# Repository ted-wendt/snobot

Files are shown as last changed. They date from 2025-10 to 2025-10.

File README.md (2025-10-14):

# Project Sno-bot
A modular, Raspberry-Pi–driven sidewalk snow-removal robot designed for Helena, MT conditions. This repo is organized for **clarity, reproducibility, and future contributions**.

## Highlights
- **Modular Toolhead Interface**: swap plow, brush, or blower without rewiring
- **Teleop → Autonomy Path**: same electronics, two software modes
- **Pi-first, lightweight ML**: semantic segmentation on-device; TFLite/ONNX
- **Safety-first**: E‑stop, contactor, current-based jam detection

## Repo Layout
```
project-sno-bot/
├── README.md
├── LICENSE
├── .gitignore
├── docs/
│   ├── architecture.md
│   ├── toolhead_interface.md
│   ├── autonomy_plan.md
│   ├── casting_planner.md
│   └── vision_pipeline.md
├── electronics/
│   ├── parts_list.md
│   ├── wiring.md
│   └── schematics/   (place PDFs/PNGs here)
├── firmware/
│   └── toolhead_mcu/
│       ├── README.md
│       └── examples/
│           ├── i2c_api_sketch.ino
│           ├── can_api_sketch.md
│           └── id_eeprom_schema.json
├── software/
│   ├── pi/
│   │   ├── toolhead_manager.py
│   │   ├── teleop_controller.py
│   │   ├── requirements.txt
│   │   └── examples/
│   │       └── demo_run.py
│   └── training/
│       ├── dataset_prep.md
│       ├── fastscnn_train_stub.py
│       └── export_to_tflite.md
└── mechanical/
    ├── mount_interface.md
    └── references.md
```

## Quick Start
1. **Clone** this repo and open `docs/architecture.md`.
2. **Electronics**: follow `electronics/parts_list.md` and `electronics/wiring.md`.
3. **Firmware**: flash `firmware/toolhead_mcu/examples/i2c_api_sketch.ino` to your toolhead MCU.
4. **Software (Pi)**: install `software/pi/requirements.txt` then run `examples/demo_run.py`.
5. **Vision**: see `docs/vision_pipeline.md` and `software/training/` for segmentation training.

## License
MIT — see `LICENSE`.

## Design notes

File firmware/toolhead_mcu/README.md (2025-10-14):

# Toolhead MCU

Provide a uniform API to the Pi regardless of attachment (brush/thrower/plow).

- Enforce local safety (overcurrent → FAULT)
- Jam clear routine (reverse X ms, retry N)
- Servo control for chute/deflector
- Report: type, currents, rpm, temp, faults

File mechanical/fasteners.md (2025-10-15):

# Fasteners & Hardware

## T-slot
- Roll-in spring T-nuts, M5: 60 pcs
- Button head M5 x 10 mm: 60 pcs
- Corner bracket kits (include bolts & T-nuts): 12–20 kits

## Through-bolts
- M6 x 16/20 mm + washers + nyloc (nose plate): 6 pcs
- M5 x 12/16 mm + washers + nyloc (belly pan): 8 pcs
- Add M6 for gussets/front bar: 8 pcs

## Bearings/Shafts (if jackshafts)
- Pillow blocks UCP201 (12 mm) or UCP202 (15 mm): 4 pcs
- Keyed shaft 12–15 mm: 2 short lengths
- Shaft collars (matching ID): 4 pcs

## Notes
- Prefer stainless hardware where exposed; blue Loctite 243; anti-seize for stainless.
- Heat-set inserts (M3/M4) for printed parts.

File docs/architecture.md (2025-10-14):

# System Architecture

## Goals
- Helena snowbanks: must **lift/throw** snow (not just push)
- **Modular toolhead** with uniform electrical + software interface
- **Teleop now, autonomy later** without electronics redo

## High-Level Diagram
- **Compute**: Raspberry Pi (teleop + autonomy)
- **Traction**: Pololu motor HAT (left/right)
- **Toolhead**: Swappable module with its own MCU + drivers
  - BLDC impeller via **VESC** (UART/CAN)
  - Brushed DC auger/actuators via **H-bridge**
  - Servos (chute/deflector) via PCA9685 or MCU PWM
- **Safety**: E‑stop → DC contactor; guard/cover interlock; current sensing
- **Perception**: mono camera → segmentation (Fast‑SCNN/ENet) → drivable ribbon
- **Localization**: wheel odom + IMU (optional LiDAR later)
- **Planner**: centerline follow + “no‑throw” map → chute angles

## Operating Modes
- **DISARMED** → **ARMED** → **TELEOP** or **AUTO** → **FAULT**/E‑STOP
- Teleop has priority; MCU enforces current limits + jam clear.

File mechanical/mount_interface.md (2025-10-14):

# Mechanical Mount Interface (Draft)
- Quick‑attach face plate with 4× M6 slots, 50×50 mm pattern
- Datum surface 20 mm above ground; adjustable skid shoes ±10 mm
- Cable strain relief + IP‑rated connector orientation downward

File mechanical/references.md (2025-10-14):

# Mechanical References
- Snow blower single‑stage paddle geometries
- Off‑the‑shelf scooter BLDCs for impellers
- 80/20 aluminum extrusions for brackets

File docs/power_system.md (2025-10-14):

# Power System (24 V Toolhead Rail + 5 V Logic)

This guide covers a robust, reproducible power setup for Sno‑bot.

## Architecture Overview
- **Toolhead Rail:** 24–26 V (preferred: **8S LiFePO₄ 25.6 V** or **6S LiPo 22.2 V**)
- **Logic/Compute:** 5 V from a high‑quality buck converter (≥5–8 A)
- **Traction:** share the 24 V rail (separate motor drivers) _or_ keep 12 V during early tests
- **Isolation:** separate toolhead rail from logic; common ground at a star point

```
Battery (24–26 V) → Main Fuse (40–60 A) → Contactor (E‑STOP) →
    ├─ VESC (BLDC impeller/brush)
    ├─ H‑Bridge (brushed auger/actuators)
    ├─ Buck 24→5 V (Pi/servos/sensors)
    └─ Optional Buck 24→12 V (lights, relays)
```

## Sizing & Budget
Typical continuous power while clearing: **500–1200 W**.
- Drive (2 wheels): 80–200 W cruise; 400–600 W spikes on pivots
- Toolhead: 300–1200 W depending on brush/single‑stage/two‑stage
- Electronics: 10–20 W

**Runtime example** (24 V × 20 Ah LiFePO₄ ≈ 512 Wh; ~85% usable ≈ 435 Wh):
- Light: 350 W → ~1.24 h
- Moderate: 600 W → ~0.72 h
- Heavy: 1000 W → ~0.44 h

## Chemistry Choices
| Chemistry | Pros | Cons | Notes |
|---|---|---|---|
| **LiFePO₄ (8S, 25.6 V)** | Safe, long cycle life, integrated BMS | Heavier; **don’t charge <0 °C** | Best for reproducible builds |
| **LiPo (6S, 22.2 V)** | Light, high C, cheap | Touchier safety, cold sag, no BMS | Fine for prototypes & short demos |
| **Li‑ion (6–7S)** | Good energy density | Pack build complexity | Viable if you already build packs |

## Cold‑Weather Guidance
- **Don’t charge LiFePO₄ below 0 °C.** Discharge is OK with reduced capacity.
- Insulate the battery; add a **5–10 W heater pad** with a **5 °C thermostat**.
- Use **soft‑start** on toolhead motors (VESC ramp; H‑bridge PWM ramp).

## Current, Wire, Fusing
- Size for **50–60 A** bursts at 24 V.
- **Main fuse:** 40–60 A (MIDI/ANL) close to the battery.
- **Contactor/relay:** DC‑rated ≥60 A on 24 V.
- **Wire:** 10 AWG for 30–40 A runs; 8 AWG if long. Keep logic wiring separate/twisted.
- **Connectors:** **XT90‑S (anti‑spark)** or **Anderson SB50** on the toolhead rail.

## Safety Chain
- Physical **E‑STOP** in series with the **contactor coil**.
- **Guard/cover switch** in the ENABLE loop to prevent spin when open.
- **Current sensors** (INA226/ACS758) to detect jams; auto‑reverse auger.

## Using Your Existing 3S 11.1 V 5 Ah Packs
- Two in series = **6S 22.2 V 5 Ah ≈ 111 Wh** → short demos.
- For production, move to a **single 24 V LiFePO₄ pack with BMS** (20–30 Ah).

## Checklists

### Bring‑Up
- [ ] Battery secured, insulated, and strain‑relieved
- [ ] Main fuse within 10 cm of battery positive
- [ ] Contactor wired through E‑STOP and key/arm switch
- [ ] Star ground near contactor; logic return routed separately
- [ ] Buck converters mounted with airflow
- [ ] Current sensors calibrated (zero, scale)
- [ ] ESC/H‑bridge soft‑start verified; no brownouts on spin‑up

### Field Operation
- [ ] Battery at room temperature before charging
- [ ] Visual inspection for damaged chains/wires
- [ ] E‑STOP test before engaging toolhead
- [ ] Logs enabled for current, voltage, RPM (for later tuning)

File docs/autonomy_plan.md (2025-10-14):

# Autonomy Plan

## Perception
- Binary semantic segmentation: **sidewalk vs non‑sidewalk**
- Model: **Fast‑SCNN / ENet / BiSeNetV2** at 384×192 or 512×256
- Export: **TFLite INT8** or **ONNX**

## Post‑Processing
- Morphological clean → largest component near bottom
- Row‑wise centroid → polynomial centerline
- Chute planner: segment‑based allowed azimuth ranges

## Mapping
- Pre‑season clear‑ground mapping: mark **no‑throw** polygons and **dump zones**
- During storm: align via odom/IMU; optional VO/LiDAR later

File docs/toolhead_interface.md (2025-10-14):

# Toolhead Interface (Electrical + Software)

## Electrical Connector (example)
- Power: **+V_tool**, **GND**
- Safety: **ENABLE loop** (series with E‑stop + guard switch)
- Bus: **I²C** (SDA/SCL) *or* **CAN** (H/L)
- Aux: 2–4 pins for PWM/DIR/servo if needed
- ID: analog ID pin *or* I²C EEPROM (24LC02) with JSON blob

## Toolhead MCU Responsibilities
- Drive local motors (VESC over UART/CAN; H‑bridge PWM/DIR)
- Servo control for chute/deflector
- Read sensors (current, RPM, temp, lid)
- Implement **state machine**: IDLE → SPINUP → RUN → JAM_CLEAR → FAULT
- Expose uniform API to Pi

## Uniform API (I²C example)
- `0x01 SET_ENABLE {0|1}`
- `0x02 SET_THROTTLE {-100..100}` (or `SET_RPM` for BLDC)
- `0x03 SET_DIR {FWD|REV}`
- `0x04 SET_CHUTE_DEG {0..360}`
- `0x05 SET_DEFLECT_PCT {0..100}`
- `0x10 GET_STATUS` → currents, rpm, temp, faults, type

See `firmware/toolhead_mcu/examples/i2c_api_sketch.ino`.

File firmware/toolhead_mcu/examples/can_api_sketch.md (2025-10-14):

# CAN API Sketch
If you choose CANbus, mirror the same commands with 11-bit IDs:
- 0x100: SET_ENABLE, payload 1 byte
- 0x101: SET_THROTTLE, payload 1 byte (signed)
- 0x102: SET_DIR, payload 1 byte
- 0x103: SET_CHUTE, payload 2 bytes (deg)
- 0x104: SET_DEFLECT, payload 1 byte
- 0x180: GET_STATUS → periodic 10 Hz frame (currents, rpm, temp, faults)

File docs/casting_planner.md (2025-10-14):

# Casting Planner (Snow Throw Direction)

## Inputs
- Segment ID (from route)
- Wind (optional)
- No‑throw polygons
- Bank height estimate (optional, later)

## Outputs
- Chute azimuth (deg) + deflector (%)
- Safety check: if no safe azimuth, pause and re‑approach

## State Sketch
- `APPROACH` → `CAST_ALLOWED?` → `SET_AZIMUTH` → `TRACK_SEGMENT` → loop

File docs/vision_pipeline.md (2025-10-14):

# Vision Pipeline

## Dataset
- ~300 images of snow‑covered sidewalks
- Masks labeled as `sidewalk`

## Augmentations
- Brightness/contrast/gamma, light blur, noise
- Haze/fog, low‑contrast variants
- Small rotations, flips if context allows

## Training (PyTorch)
- Loss: BCEWithLogits + Dice (or Focal + Dice)
- Optim: AdamW, LR 3e‑4, 50–100 epochs
- Metric: IoU on sidewalk class

## Export
- PyTorch → ONNX → TFLite INT8 (post‑training quant)

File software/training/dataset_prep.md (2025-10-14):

# Dataset Preparation
- Use CVAT/LabelMe to annotate sidewalks → binary masks.
- Split 70/15/15 train/val/test by scene (avoid leakage).
- Resize to 384×192 or 512×256; save RGB + mask pairs.

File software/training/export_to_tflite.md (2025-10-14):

# Export to TFLite
- Export PyTorch → ONNX (opset 12)
- Convert ONNX → TF SavedModel → TFLite (INT8 post‑training)
- Copy .tflite to Pi and run via tflite-runtime

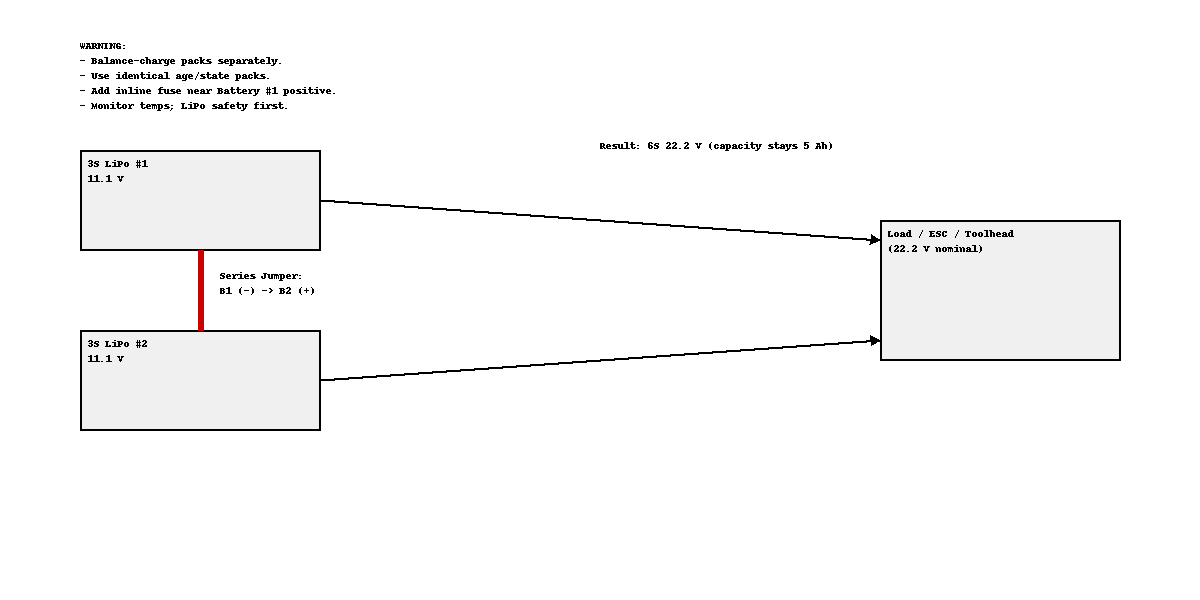
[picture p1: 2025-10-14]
electronics/schematics/series_harness_2x3S_to_6S.png

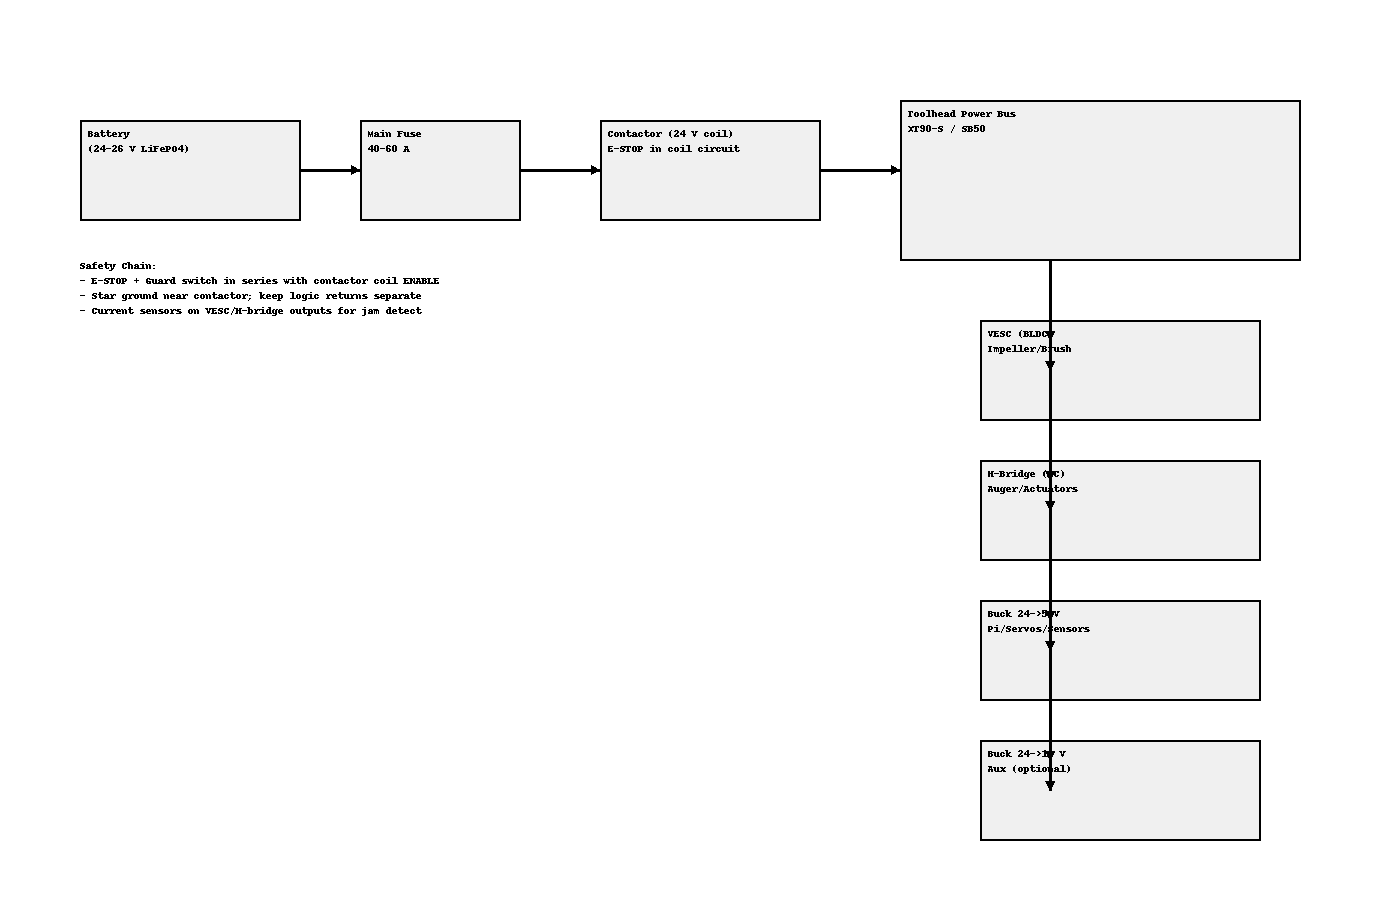
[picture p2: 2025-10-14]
electronics/schematics/power_overview_schematic.png

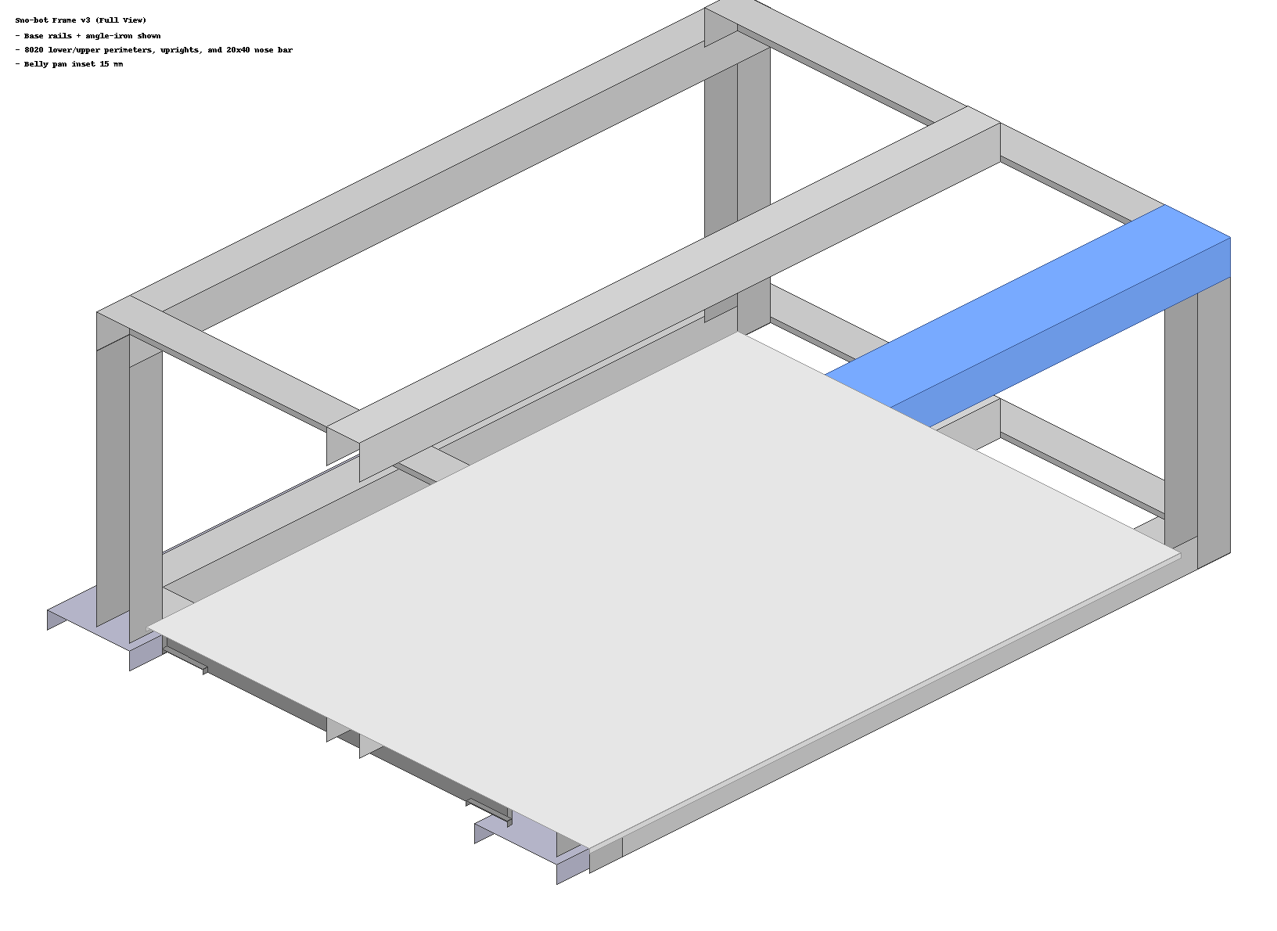
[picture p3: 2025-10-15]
docs/frame_visual_v3.png

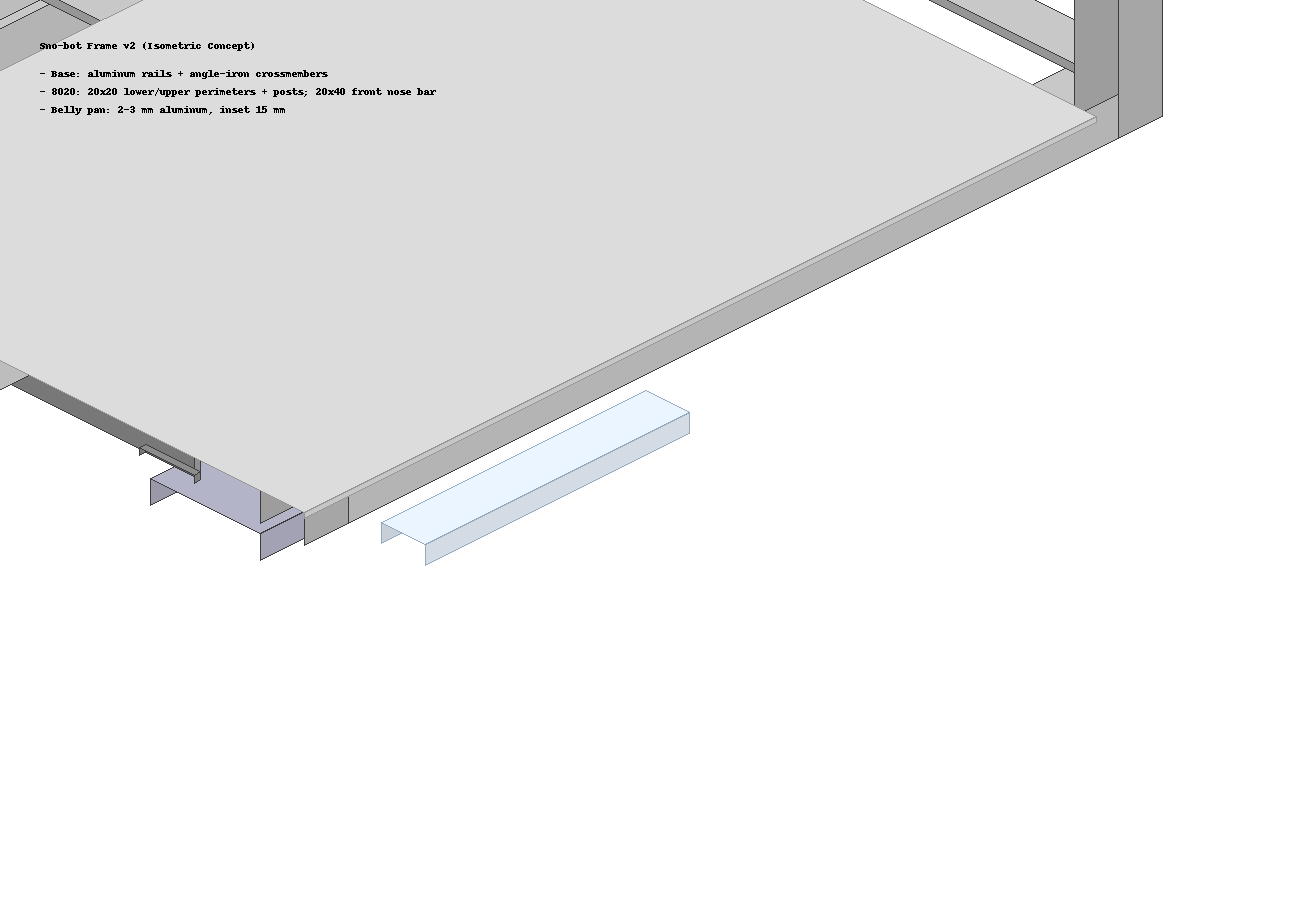
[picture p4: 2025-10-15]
docs/frame_visual_v2.png

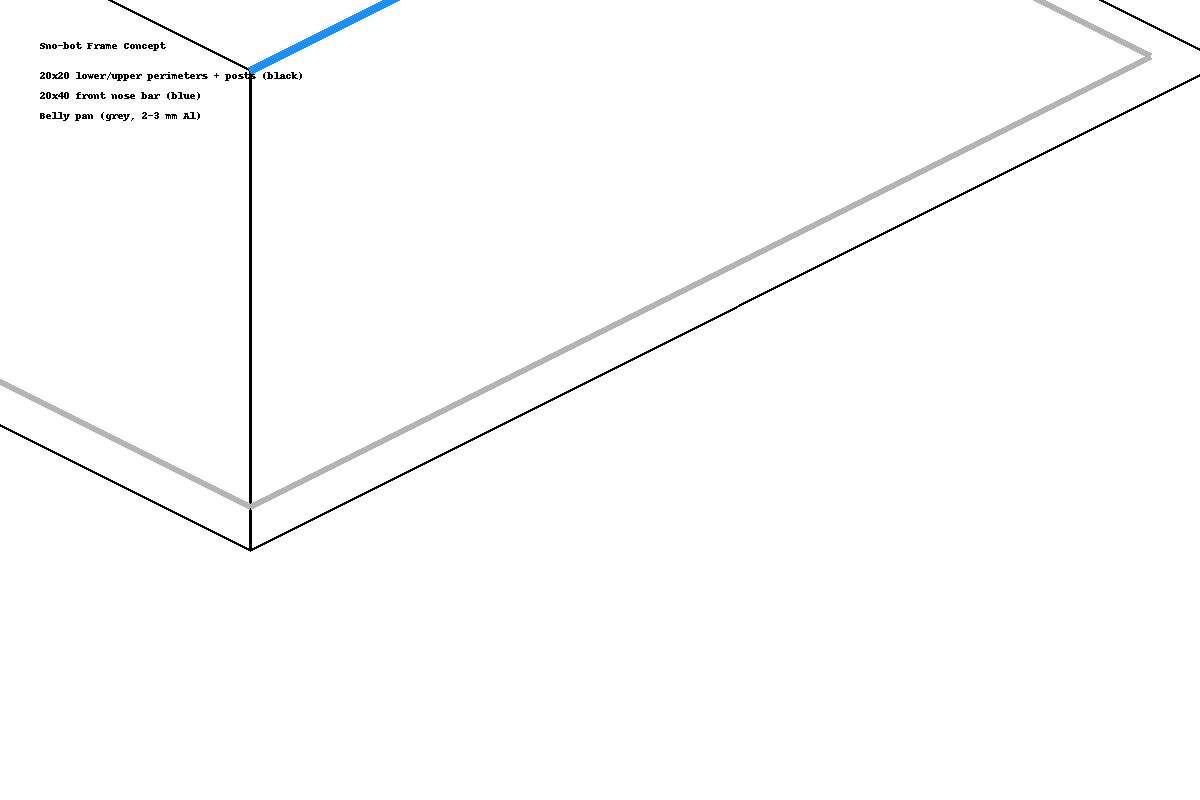
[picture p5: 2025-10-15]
docs/frame_visual.png

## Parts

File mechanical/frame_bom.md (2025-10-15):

# 8020 Superstructure BOM (Starter)

## Extrusions (20-series)
- 20x20mm:
  - Lower perimeter: 2x 390 mm, 2x 300 mm
  - Upper perimeter: 2x 390 mm, 2x 300 mm
  - Posts: 4x 160 mm
  - Mid crossmembers: 2x 300 mm
- 20x40mm:
  - Front nose bar: 1x 300 mm

## Plates
- Belly pan: Aluminum 360 x 270 x 2–3 mm (DXF included)
- Nose plate: Aluminum 300 x 120 x 6 mm (DXF included)
- Battery tray: ~260 x 160 x 2–3 mm (drill to suit)

## Brackets
- Heavy corner brackets 20-series: 12 pcs
- Small L-brackets: 8 pcs
- Optional internal anchor fasteners: 12 pcs
- Optional gussets (front posts to nose bar): 4 pcs

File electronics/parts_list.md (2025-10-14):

## Power System Add‑Ons

| Item | Example | Qty | Est. USD |
|---|---|---:|---:|
| **Battery (preferred)** | 24–26 V **LiFePO₄ 20–30 Ah** with BMS | 1 | 180–350 |
| Battery (prototype) | 6S LiPo 22.2 V 5–10 Ah (use 2×3S in series if on hand) | 1 | 60–160 |
| **Main Fuse** | MIDI/ANL 40–60 A + holder | 1 | 10–25 |
| **DC Contactor** | 24 V coil, ≥60 A DC | 1 | 15–40 |
| **E‑STOP switch** | Latching mushroom | 1 | 8–20 |
| **Heater Pad + Thermostat** | 5–10 W pad, 5 °C on | 1 | 15–30 |
| **Buck 24→5 V** | 5–8 A continuous | 1 | 10–25 |
| Optional Buck 24→12 V | 5–10 A for auxiliaries | 1 | 10–25 |
| **Connectors (tool rail)** | **XT90‑S** (anti‑spark) or **Anderson SB50** | — | 10–30 |
| **Wiring** | 8–10 AWG silicone + ferrules | — | 15–35 |
| **Current Sensors** | INA226 (I²C) or ACS758 (analog) | 2 | 16–40 |
| Battery Meter (optional) | Inline volt/amp gauge or shunt | 1 | 10–30 |

See `docs/power_system.md` for architecture and checklists.

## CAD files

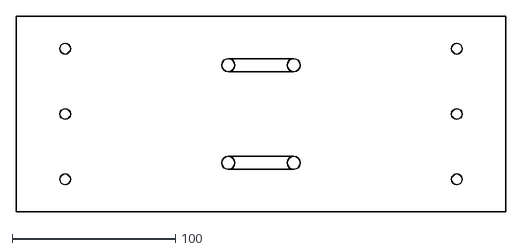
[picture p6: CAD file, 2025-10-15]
mechanical/drawings/nose_plate_300x120mm.dxf
300.0 x 120.0

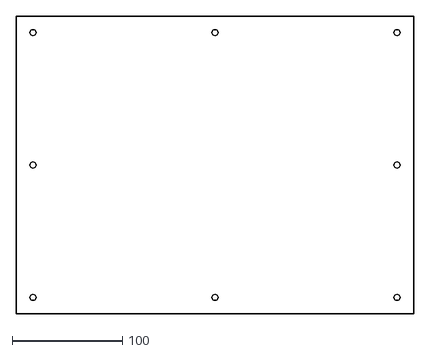
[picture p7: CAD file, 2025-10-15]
mechanical/drawings/belly_pan_360x270mm.dxf
360.0 x 270.0

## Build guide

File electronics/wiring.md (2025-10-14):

# Wiring Overview

## Power Domains
- Pi 5 V (isolated, buck converter)
- Toolhead rail (24–36 V) → **Main fuse** → **Contactor** → Drivers/ESC

## Safety Chain
`E‑STOP` + `Guard switch` in series with **ENABLE** to toolhead MCU/contactor coil.

## Signals
- Pi ↔ Toolhead MCU: I²C (or CAN)
- MCU ↔ VESC: UART (or CAN)
- MCU ↔ H‑bridge: PWM + DIR + EN
- Pi ↔ PCA9685: I²C (if servos not on MCU)

## Telemetry
- Current sensors to MCU (I²C or analog ADC)
- Optional INA219/226 on battery rail for logging

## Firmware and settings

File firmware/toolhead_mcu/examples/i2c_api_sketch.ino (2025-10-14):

// Minimal pseudo‑sketch for a toolhead MCU I²C API
// MCU: Arduino/Teensy/STM32; wire up to Pi I²C
#include <Wire.h>

#define I2C_ADDR 0x2A
#define CMD_SET_ENABLE 0x01
#define CMD_SET_THROTTLE 0x02
#define CMD_SET_DIR 0x03
#define CMD_SET_CHUTE 0x04
#define CMD_SET_DEFLECT 0x05
#define CMD_GET_STATUS 0x10

volatile bool enabled=false;
volatile int8_t throttle=0;     // -100..100
volatile int8_t direction=1;    // 1 fwd, -1 rev
volatile uint16_t chute_deg=0;  // 0..360
volatile uint8_t deflect_pct=0; // 0..100

void receive(int n){
  if(n<1) return;
  uint8_t cmd = Wire.read();
  switch(cmd){
    case CMD_SET_ENABLE: enabled = Wire.read(); break;
    case CMD_SET_THROTTLE: throttle = (int8_t)Wire.read(); break;
    case CMD_SET_DIR: direction = Wire.read()?1:-1; break;
    case CMD_SET_CHUTE: chute_deg = (Wire.read()<<8) | Wire.read(); break;
    case CMD_SET_DEFLECT: deflect_pct = Wire.read(); break;
  }
}

void request(){
  // Return 8 bytes: type, faults, curr_hi, curr_lo, rpm_hi, rpm_lo, temp, reserved
  uint8_t type = 2; // 1=plow,2=thrower,3=brush (demo)
  uint8_t faults = 0;
  uint16_t curr = 123; // mA demo
  uint16_t rpm  = 2500;
  uint8_t tempC = 30;
  Wire.write(type);
  Wire.write(faults);
  Wire.write((uint8_t)(curr>>8)); Wire.write((uint8_t)(curr&0xFF));
  Wire.write((uint8_t)(rpm>>8));  Wire.write((uint8_t)(rpm&0xFF));
  Wire.write(tempC);
  Wire.write(0);
}

void setup(){
  Wire.begin(I2C_ADDR);
  Wire.onReceive(receive);
  Wire.onRequest(request);
  // init drivers/ESC/servos here
}
void loop(){
  // apply throttle/dir to drivers
  // jam detect & clear
}
